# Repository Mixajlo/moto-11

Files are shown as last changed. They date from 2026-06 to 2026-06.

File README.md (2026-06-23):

# moto-11

A modular **ESP32 smart-cockpit, accessory, and security system** for a 2013 Suzuki
V-Strom DL650 — hardware, firmware, harness, and documentation in one repository.

The guiding philosophy is **"fairings off once"**: provision generously now, upgrade in
place later. The ESP32 owns all bike logic; a tablet is a thin display; the phone handles
navigation and connectivity.

---

## What it is

`moto-11` turns the bike into a programmable platform without making any consumer device a
single point of failure:

- **Bike-side controller** — an ESP32-WROOM-32D that is always-hot, deep-sleeps when parked,
  and wakes on ignition. It is the single source of truth for relay control, sensing,
  load management, security, and the parked sentinel.
- **Dashboard** — an Android tablet acting as a *thin* BLE display and an Android Auto
  receiver. UI only; it never decides anything.
- **Phone** — navigation, connectivity, and the BLE relay that drains the bike's event queue
  when it's parked out of network range.

It also folds in the unglamorous-but-important electrical work: a series R/R charging upgrade,
relieving the notorious headlight-through-the-starter-switch wiring, accessory switching via a
relay box driven by a ULN2803, and battery/charging telemetry from an INA226.

## Status

**Early development.** OTA firmware (WiFi + ArduinoOTA + heartbeat) is proven on the bench
across both ESP units. Relay control and the **engine-run supervisor** are in and
bench-validated: a `RelayController` drives the four ULN2803 coil enables (fail-OFF at boot),
a serial/Telnet **bench console** actuates them by hand, and the supervisor runs the power
state machine — `SLEEP → ARMED → RUNNING ⇄ POWERED` (+ `OFF_DELAY`) with ignition-as-master,
a battery backstop, and a charge-health warning — driven by simulated sensors and covered by
unit tests. Next firmware milestone: the real **INA3221** driver + PC817 ignition-sense (then
flip `sim real`), and load-shedding. Hardware is at the bench-prototyping stage (KiCad schematic
+ first-pass PCB). See `docs/adr/` for the decisions made so far.

## Architecture

```
        ┌─────────────┐    BLE     ┌──────────────────────┐
        │   ESP32     │◄──────────►│  Tablet (thin UI +   │
        │ authoritative│            │  Android Auto recv)  │
        │ controller   │            └──────────────────────┘
        └──────┬───────┘                       ▲ projects
   I²C / GPIO / │ relays                        │ Android Auto
  ┌─────────────┼───────────────┐        ┌──────┴──────┐
  │ INA226  IMU  ULN2803  opto   │        │   Phone     │
  │ relay box   master relay     │        │ nav + relay │
  └──────────────────────────────┘        └─────────────┘
```

The ESP runs the bike; the tablet renders; the phone connects. A tablet reboot or removal
degrades only the UI, never the bike's function. Full reasoning is in
[`docs/adr/0001`](docs/adr/0001-esp32-authoritative-controller.md).

## Repository layout

```
moto-11/
├── CLAUDE.md          # project context for Claude Code (read first)
├── firmware/          # PlatformIO ESP32 project        (MIT)
│   ├── platformio.ini
│   ├── src/main.cpp
│   └── include/secrets.h.example
├── hardware/          # KiCad / relay-box as-built       (CERN-OHL-P)
├── harness/           # WireViz source + rendered output
├── docs/              # design docs + decision records    (CC-BY-4.0)
│   ├── electrical-plan.html
│   ├── wiring-schematic.html
│   └── adr/
└── app/               # future tablet / Android Auto app
```

## Hardware

| Area | Choice |
|---|---|
| Controller | ESP32-WROOM-32D (×2: bench twin + bike unit) |
| Charging | Series R/R (Shindengen SH775 / SH847); stock stator, measured first |
| Accessory switch| Pre-wired 4-relay / 6-fuse box, gated by an external master relay |
| Coil driver | ULN2803A (low-side, internal flyback) |
| Sensing | INA226 (bus voltage) + PC817 opto-isolated 12 V inputs + 6-axis IMU |
| Dashboard | Android tablet (Galaxy Tab Active5 target) + phone |

The authoritative electrical design is in `docs/electrical-plan.html` (23 sections) and
`docs/wiring-schematic.html` (single-sheet wiring + ULN2803 driver detail).

## Getting started (firmware)

### Prerequisites
- [VS Code](https://code.visualstudio.com/) with the **PlatformIO IDE** extension
- **Silicon Labs CP210x USB-to-UART driver** (the ESP boards use a CP2102 — without it Windows
  shows no COM port)
- Git

### Clone and open
```bash
git clone https://github.com/<you>/moto-11.git
```
Open the **`firmware/`** subfolder in VS Code (`File → Open Folder → moto-11/firmware`).
PlatformIO expects `platformio.ini` at the root of the opened folder, so open `firmware/`
directly — not the repo root. (Git still tracks the whole repo.) On the first build,
PlatformIO downloads the ESP32 toolchain and framework; let it finish.

### Configure secrets
Copy the template and fill it in — it is gitignored, so your credentials never reach the repo:
```bash
cp include/secrets.h.example include/secrets.h
```
Set `WIFI_SSID`, `WIFI_PASS`, and an `OTA_PASS`. The `OTA_PASS` must match the `--auth=` value
in `platformio.ini`. Avoid `%` and `$` in the OTA password (the config parser treats them
specially).

### Build, flash, monitor
One codebase builds two devices via separate environments (`bench` / `bike`), distinguished by
`DEVICE_NAME`. First flash of each device is over USB:
```bash
pio run -e bench                 # build
pio run -e bench -t upload       # flash over USB
pio device monitor               # serial logs @ 115200
```
Swap `bench` → `bike` for the second unit. (In VS Code, the PlatformIO **Project Tasks** panel
exposes Build / Upload / Monitor per environment — use those rather than the status-bar buttons,
which act on whatever environment is selected.)

### OTA updates
After the first USB flash, update wirelessly:
```bash
pio run -e bench_ota -t upload
```
Set the device's IP (from the serial log) as `upload_port` in the `*_ota` environment if the
`.local` mDNS name doesn't resolve on your OS.

### Windows OTA gotcha
ArduinoOTA needs the ESP to open a connection *back* to your PC. Two things block this on
Windows:
- **Extra network adapters** (WSL/Hyper-V `vEthernet`, VMware, VirtualBox, VPN) — espota can
  advertise the wrong host IP. Disable them so only your real LAN/Wi-Fi adapter is active.
- **A third-party antivirus firewall** — independent of the Windows firewall; pause its network
  shield for the push.

Symptom is `Authenticating…OK` followed by `Waiting for device… No response`. See
[`docs/adr/0008`](docs/adr/0008-ota-ab-rollback.md).

## Documentation

- **[Bench relay guide](https://mixajlo.github.io/moto-11/bench-relay-guide.html)** —
  step-by-step: flash the firmware and click the relays on the bench (just an ESP + USB to
  start). Good first hands-on walkthrough. (Source: `docs/bench-relay-guide.html`.)
- **Design docs** — published via **GitHub Pages** from `/docs`:
  [home](https://mixajlo.github.io/moto-11/),
  [electrical plan](https://mixajlo.github.io/moto-11/electrical-plan.html),
  [wiring schematic](https://mixajlo.github.io/moto-11/wiring-schematic.html).
- **Decision records** (`docs/adr/`) — the *why* behind every major choice, Nygard-format.
- **`CLAUDE.md`** — the condensed project brief; also what Claude Code reads on startup.

## Design principles

- **Colourblind-safe output, always.** Every diagram, chart, and UI uses the Okabe-Ito palette
  and never encodes meaning by colour alone — colour is always paired with line pattern and a
  text label. The maintainer is colourblind; this is a hard constraint.
- **Fail-safe by direction.** Accessories fail **OFF** (safe when the ESP dies); headlights fail
  **ON**. Safety-critical lighting is never solely behind the controller.
- **Bench-twin-first.** Every change is proven on the bench twin before it reaches the bike.

## Licensing

This repo is multi-licensed by content type:

| Path | License |
|---|---|
| `firmware/`  | MIT |
| `hardware/`  | CERN-OHL-P-2.0 |
| `harness/` | CERN-OHL-P-2.0 |
| `docs/` | CC-BY-4.0 |

Full texts live in `LICENSES/`. SPDX identifiers in file headers make this machine-readable;
the [REUSE](https://reuse.software) tool lints it.

## Disclaimer

This project modifies a motorcycle's electrical, charging, and lighting systems. Do this only
if you understand the risks — incorrect wiring can damage the bike, the battery, or yourself,
and some changes (e.g. lighting behaviour) may be subject to local road regulations. Use at your
own risk. Not affiliated with or endorsed by Suzuki.

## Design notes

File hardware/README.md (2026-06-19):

<!-- SPDX-License-Identifier: CERN-OHL-P-2.0 -->
# moto-11 — hardware

KiCad designs and as-built notes for the bike electronics. Licensed **CERN-OHL-P-2.0**
(permissive open hardware) — full text in [`../LICENSES/`](../LICENSES/).

> **Hardware safety:** this drives a motorcycle's 12 V electrical system. Nothing here is
> proven until it's bench-tested per the [bench relay guide](../docs/bench-relay-guide.html).
> Fail-safe direction is non-negotiable: accessories fail **OFF**, headlights fail **ON**.

## Boards

| Board | What it is | Status |
|---|---|---|
| [`mainboard/`](mainboard/) | ESP32-DevKitC carrier + ULN2803 coil driver + sensing front-end (INA226, PC817 opto, IMU) + connectors. Drives the **existing** pre-wired relay/fuse box; it does **not** carry load current. | 📐 design package (pre-KiCad) |

The pre-wired 4-relay / 6-fuse box and the external master relay stay as discrete parts — the
mainboard is the brain that drives their coils and senses the bus. High load current (fog,
grips, tablet) never flows through this PCB.

## How this is organised

Per the chosen workflow, the design is captured as a **text design package** first, then drawn
in KiCad from it:

- [`mainboard/01-schematic-spec.md`](mainboard/01-schematic-spec.md) — the schematic as a
  component list + net-by-net connection table. This is the source of truth for capture.
- [`mainboard/02-bom.csv`](mainboard/02-bom.csv) — bill of materials with part numbers.
- [`mainboard/03-design-rules.md`](mainboard/03-design-rules.md) — board stackup, trace widths
  (sized from real currents), clearances, connectors, mechanical.
- [`mainboard/04-kicad-guide.md`](mainboard/04-kicad-guide.md) — step-by-step to turn the spec
  into a KiCad schematic + PCB, with DRC and fab outputs.

KiCad project files (`*.kicad_pro/_sch/_pcb`) land in `mainboard/` once capture begins.

## Toolchain

**KiCad 10.0.3** is installed on the build machine. Start with
[`04-kicad-guide.md`](mainboard/04-kicad-guide.md). The capture/layout workflow is stable across
KiCad 8–10, so the guide applies regardless of minor version.

## Cross-references

- GPIO pin map: [ADR-0009](../docs/adr/0009-gpio-pin-map.md) (this board adds two pins — see the
  schematic spec's *open decisions*).
- Coil driver rationale: [ADR-0003](../docs/adr/0003-uln2803-coil-driver.md).
- Master-relay gating / fail-safe: [ADR-0004](../docs/adr/0004-master-relay-gating-and-failon-headlights.md).
- Sensing: [ADR-0005](../docs/adr/0005-ina226-sensing.md).
- Authoritative electrical design: [`../docs/electrical-plan.html`](../docs/electrical-plan.html)
  and [`../docs/wiring-schematic.html`](../docs/wiring-schematic.html).

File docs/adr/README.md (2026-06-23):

# Architecture Decision Records

Short records of the significant decisions on **moto-11** — the *why* behind the build, so
future choices (and Claude Code) start with the full context instead of re-deriving it.

One file per decision, named `NNNN-short-title.md`, following Michael Nygard's template
(see `template.md`). A decision's `Status` moves Proposed → Accepted; when a later decision
overturns an earlier one we add a new ADR and mark the old one *Superseded* rather than
editing history.

## Index
- [0001](0001-esp32-authoritative-controller.md) — ESP32 as the authoritative controller; tablet as a thin BLE dashboard
- [0002](0002-series-rr-over-mosfet.md) — Series R/R over a MOSFET (shunt) regulator
- [0003](0003-uln2803-coil-driver.md) — ULN2803 coil driver; commoned pin 86 reused as +12, low-side on pin 85
- [0004](0004-master-relay-gating-and-failon-headlights.md) — External master relay gates the box; headlights stay outside it (fail-ON)
- [0005](0005-ina226-sensing.md) — INA226 for engine-run detection and battery telemetry; sense on a clean lead
- [0006](0006-layered-connectivity.md) — Layered connectivity: phone-relay BLE when parked, tablet radio when riding
- [0007](0007-can-reserved-sds-is-kline.md) — CAN reserved for own modules; the bike's data is K-line SDS, not CAN
- [0008](0008-ota-ab-rollback.md) — OTA with A/B rollback; bench-twin-first
- [0009](0009-gpio-pin-map.md) — ESP32 GPIO pin map: relay enables, ignition sense, I²C
- [0010](0010-twelve-volt-sense-opto.md) — 12 V sense front-end: PC817 opto over a resistor divider
- [0011](0011-ina3221-replaces-ina226.md) — INA3221 (3-channel) in place of the INA226 (amends 0005)
- [0012](0012-ignition-master-switch-powered-state.md) — Ignition-as-master-switch; RUNNING vs POWERED; battery backstop; charge warning (refines §13)
- [0013](0013-runtime-config-nvs-console.md) — Runtime-configurable tunables: NVS-backed, console-edited (BLE/app later)
- [0014](0014-aux-button-inputs-per-gpio.md) — Aux button inputs: one-wire-per-button, per-GPIO, JST-XH connector

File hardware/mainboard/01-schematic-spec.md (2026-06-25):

<!-- SPDX-License-Identifier: CERN-OHL-P-2.0 -->
# Mainboard — schematic specification

The complete schematic as text: functional blocks, a component list with reference
designators, and a **net-by-net connection table**. This is the source of truth for KiCad
capture ([04-kicad-guide.md](04-kicad-guide.md)).

**What this board is:** the brain. It sockets an ESP32-DevKitC, drives the existing relay-box
coils through a ULN2803, senses the 12 V bus (INA3221) and two 12 V logic inputs (PC817 opto),
carries a 6-axis IMU, takes 8 handlebar aux buttons, and makes its own 5 V from the always-hot
battery feed. It carries only control and coil current — **never** load current.

---

## Design decisions (resolved)

1. **ESP mounting = socketed DevKitC** (2× female headers), not a bare WROOM module. Reuses
   your existing boards, keeps USB programming, matches the docs' "USB = programming-only,
   power from buck 5 V" note. *(Bare-module alternative = adds USB-UART + auto-reset + LDO; more
   parts, more risk.)*
2. **12 V sense = PC817 opto — decided.** Chosen over the divider+Zener (electrical-plan Fig 5.1)
   for transient robustness on a noisy bike bus and to keep the input-only GPIOs current-driven.
   Logic inverts (12 V present → GPIO LOW). Recorded in
   [ADR-0010](../../docs/adr/0010-twelve-volt-sense-opto.md). *(The divider+Zener stays a
   documented drop-in if you ever want fewer parts.)*
3. **Two pins added (accepted):** `START_SENSE` = **GPIO35** (input-only, RTC) = 2nd opto channel
   (start-button / headlight-feed sense); `IMU_INT` = **GPIO33** (RTC) = IMU wake-on-motion
   interrupt (deep-sleep wake source). Reflected in `firmware/src/pins.h` and
   [ADR-0009](../../docs/adr/0009-gpio-pin-map.md).
4. **Sensing IC = INA3221 (3-channel), not INA226** — the shipped part changed. Bonus: 3 channels
   → CH1 = battery bus voltage now; CH2/CH3 reserved for per-branch current sensing later (smarter
   load-shed). Watch the **26 V bus-input limit** (vs INA226's 36 V): the sense input gets a clamp
   (D3). Needs an INA3221 firmware driver (different register map). Recorded in
   [ADR-0011](../../docs/adr/0011-ina3221-replaces-ina226.md).
5. **INA3221, IMU, and buck are breakout modules on headers**, not raw chips — keeps this
   hand-solderable. *(All-SMD alternative is denser but needs reflow/hot-air.)*
6. **ULN2803 has 8 channels; only 4 are used.** The other 4 inputs/outputs are broken out to a
   header + terminals for future relays (e.g. the headlight-shed NC relay). "Fairings off once."

---

## Functional blocks

```
 +12V always-hot (fused 2A, external)
        │
   [reverse-polarity P-FET]──[TVS + bulk cap]──┬─────────────► +12V_PROT (board 12V)
        │                                      │
        │                              [MP1584 buck module A3] ──► +5V ──► ESP 5V/VIN
        │                                                                    │
        │                                                          ESP onboard LDO ──► +3V3
        │
 COIL_RAIL +12 (box pin 86, external) ──► ULN2803 COM (pin10, flyback)

 ESP GPIO 13/25/26/27 ─► ULN2803 in1..4 ─► out1..4 ─► coil 85 wires (screw terminals)
 ESP I2C 21/22 ─────────► INA3221 module + IMU module (shared bus, 4k7 pull-ups)
 12V IGN  ─► PC817 U4 ─► GPIO34 (pull-up 3V3)   [LOW when 12V present]
 12V START─► PC817 U5 ─► GPIO35 (pull-up 3V3)   [LOW when 12V present]
 IMU INT  ─────────────► GPIO33 (wake)
 BTN1..8  ─► J8 (JST-XH) ─► GPIO 4/14/16/17/18/19/23/32 (INPUT_PULLUP, active-LOW, RC)
```

---

## Power rails / nets (naming)

| Net | Meaning |
|-----|---|
| `+12V_HOT` | Always-hot battery feed, after the external 2 A inline fuse (board input). |
| `+12V_PROT` | After reverse-polarity FET + TVS — the protected board 12 V. Feeds the buck. |
| `+5V` | Buck output → ESP 5V/VIN pin. |
| `+3V3` | From the ESP DevKitC onboard regulator → powers INA3221, IMU, opto + button pull-ups. |
| `COIL_RAIL` | +12 V coil common (the box's commoned pin 86). Feeds ULN COM. Externally sourced. |
| `GND` | Single board ground; ties to the star ground externally. |

---

## Component list

| Ref | Part | Value / type | Footprint | Notes |
|-----|---|---|---|---|
| A1 | ESP32-DevKitC | ESP32-WROOM-32D module | 2× 1×19 (or 1×15) female header, 2.54 mm, 0.9″/1.0″ rows | Socketed; verify your board's pin count/row spacing. |
| A2 | IMU module | LSM6DSO (pref.) / MPU-6050 breakout | 1×5 (or 1×8) female header, 2.54 mm | 6-axis, I²C, INT out. |
| A3 | Buck module | MP1584EN mini buck | 4-pad (IN+ IN− OUT+ OUT−), 2.54 mm | Pre-set to 5.0 V **and verify** before fitting. |
| U2 | ULN2803A | Darlington array, 8-ch | DIP-18 (socketed) or SOIC-18 | Active-HIGH; COM→COIL_RAIL for flyback. |
| U3 | INA3221 module | CJMCU-3221 3-ch breakout (+ shunts) | `INA3221_Module` (custom, `mainboard.pretty`) — 1×5 labeled edge row | CH1 = bus voltage now; CH2/CH3 reserved for branch current. **26 V input max** → clamp D3. Socketed via the labeled VS/GND/SCL/SDA/A0 row; **confirm count/order** against the silk. |
| U4, U5 | PC817 | Optocoupler, single | DIP-4 | One per 12 V sense channel (IGN, START). |
| Q1 | P-MOSFET | AOD4185 / DMP3017SFG / IRF4905 | DPAK / TO-220 | Reverse-polarity (ideal-diode orientation). |
| D1 | TVS | SMBJ24A (uni, 24 V standoff) | SMB / DO-214AA | Load-dump clamp on +12V_PROT. |
| D2 | LED | green, 3 mm | THT | +3V3 power indicator (optional). |
| D3 | TVS | SMBJ20A (uni, 20 V standoff) | SMB / DO-214AA | Clamp on INA3221 sense input (26 V limit). |
| C1 | Cap | 470 µF / 35 V electrolytic | radial 8 mm | Bulk on +12V_PROT. |
| C2 | Cap | 100 µF / 16 V electrolytic | radial 6.3 mm | Bulk on +5V. |
| C3–C8 | Cap | 100 nF X7R | 0805 / THT | Decoupling: ESP, ULN, INA3221, opto, IMU. |
| C9 | Cap | 10 µF X7R | 0805 / THT | +3V3 bulk near ESP. |
| C10 | Cap | 1 µF | 0805 | RC filter on INA3221 VBUS sense. |
| R1–R4 | Res | 10 kΩ | 0805 / THT | ULN input pull-downs (boot-safe OFF). |
| R5, R6 | Res | 4.7 kΩ | 0805 | I²C SDA/SCL pull-ups to +3V3. |
| R7, R8 | Res | 2.2 kΩ, 0.25 W | THT/1206 | PC817 LED series (12 V side), ~5 mA. |
| R9, R10 | Res | 10 kΩ | 0805 | Pull-ups on GPIO34/35 (opto outputs; input-only pins). |
| R11 | Res | 100 kΩ | 0805 | Q1 gate–source. |
| R12 | Res | 100 Ω | 0805 | Q1 gate series (optional, slew). |
| Dz1 | Zener | 18 V, 0.5 W | SOD-123 / THT | Q1 gate–source clamp. >14.4 V so idle while charging; <20 V Vgs(max). |
| R13 | Res | 220 Ω | 0805 | D2 LED series. |
| R14 | Res | 100 Ω | 0805 | INA3221 sense series (light RC with C10; keep low to avoid bus-measure error). |
| J1 | Term block | 2-pos, 5.08 mm | THT | `+12V_HOT`, `GND` (power in). |
| J2 | Term block | 2-pos, 5.08 mm | THT | `COIL_RAIL` (+12 to box pin86 / ULN COM), `GND`. |
| J3 | Term block | 4-pos, 3.5 mm | THT | Coil outputs → 85 wires: MASTER, FOG, GRIP, SPARE. |
| J4 | Term block | 3-pos, 3.5 mm | THT | `IGN_12V`, `START_12V`, `SENSE_GND`. |
| J5 | Term block | 2-pos, 3.5 mm | THT | INA3221 `VBUS_SENSE` (clean lead to batt +), `GND`. |
| J6 | Header | 1×4, 2.54 mm | THT | I²C expansion: `+3V3`, `SDA`, `SCL`, `GND`. |
| J7 | Header | 2×4, 2.54 mm | THT | ULN spare ch5–8 in/out break-out (future relays). |
| J8 | Connector | JST-XH, 1×9, 2.50 mm | `Connector_JST:JST_XH_B9B-XH-A_1x09_P2.50mm_Vertical` | Handlebar aux buttons: BTN1..8 + common GND (ADR-0014). |
| R15–R22 | Res | 1 kΩ | 0805 / THT | Button series (RC with C11–C18); bench can omit, fit for the bike (noise). |
| C11–C18 | Cap | 100 nF | 0805 / THT | Button RC to GND (debounce/noise); pairs with R15–R22. |
| TP1–TP4 | Test point | — | THT loop | `+12V_PROT`, `+5V`, `+3V3`, `GND`. |

---

## ESP32-DevKitC pin usage (A1)

| GPIO | Net | Direction | Notes |
|---|-----|---|---|
| 13 | `MASTER_EN` | out | → ULN in1 |
| 25 | `FOG_EN` | out | → ULN in2 |
| 26 | `GRIP_EN` | out | → ULN in3 |
| 27 | `SPARE_EN` | out | → ULN in4 |
| 34 | `IGN_SENSE` | in | ← opto U4, pull-up R9. Input-only/RTC (ext0 wake). |
| 35 | `START_SENSE` | in | ← opto U5, pull-up R10. Input-only/RTC. *(added; ADR-0009)* |
| 33 | `IMU_INT` | in | ← IMU INT. RTC (wake-on-motion). *(added; ADR-0009)* |
| 21 | `SDA` | I/O | I²C; pull-up R5. |
| 22 | `SCL` | I/O | I²C; pull-up R6. |
| 4 | `BTN1` | in | ← `J8.1`; INPUT_PULLUP + RC (R15/C11). Active-LOW. *(ADR-0014)* |
| 14 | `BTN2` | in | ← `J8.2`; INPUT_PULLUP + RC (R16/C12). |
| 16 | `BTN3` | in | ← `J8.3`; INPUT_PULLUP + RC (R17/C13). |
| 17 | `BTN4` | in | ← `J8.4`; INPUT_PULLUP + RC (R18/C14). |
| 18 | `BTN5` | in | ← `J8.5`; INPUT_PULLUP + RC (R19/C15). |
| 19 | `BTN6` | in | ← `J8.6`; INPUT_PULLUP + RC (R20/C16). |
| 23 | `BTN7` | in | ← `J8.7`; INPUT_PULLUP + RC (R21/C17). |
| 32 | `BTN8` | in | ← `J8.8`; INPUT_PULLUP + RC (R22/C18). Spare. |
| 5V (VIN) | `+5V` | pwr in | from buck A3. |
| 3V3 | `+3V3` | pwr out | from ESP LDO → board 3V3 rail. |
| GND (×) | `GND` | pwr | tie all DevKitC GND pins. |

> Do **not** feed +5V to VIN while USB is also connected (see electrical-plan §05). On the
> bench, power via USB *or* the buck, not both.

---

## Net-by-net connection table

Every electrical node, listed by net. `A1.13` = DevKitC GPIO13; `U2.1` = ULN2803 pin 1; etc.
Decoupling caps: place one 100 nF physically next to each IC's V+/GND.

### Power & ground
| Net | Connects |
|-----|---|
| `+12V_HOT` | `J1.1`, Q1 **drain**. External 2 A fuse upstream. |
| `+12V_PROT` | Q1 **source**, `D1` cathode (TVS across PROT→GND), `C1+`, `A3.IN+`, `TP1`. |
| `+5V` | `A3.OUT+`, `C2+`, `A1.5V/VIN`, `TP2`. |
| `+3V3` | `A1.3V3`, `U3.VS`/`U3.VCC`, `A2.VCC`, `R5`, `R6`, `R9`, `R10`, `D2`(via R13), `C9+`, `TP3`. |
| `GND` | `J1.2`, `J2.2`, `A3.IN−`, `A3.OUT−`, `A1.GND`, `U2.9`, `U3.GND`, `U4.gnd side`, `U5.gnd side`, `A2.GND`, `J4.SENSE_GND`, `J5.2`, `J6.4`, all cap −, `TP4`. |
| `COIL_RAIL` | `J2.1`, `U2.10 (COM)`. (Externally wired to box pin 86.) |

### Reverse-polarity + TVS (input protection)
| Net | Connects |
|-----|---|
| Q1 gate | → `GND` via `R12` (100 Ω series); `R11` (100 k) gate→source; `Dz1` zener gate→source clamp. |
| `D1` (TVS) | cathode → `+12V_PROT`, anode → `GND` (unidirectional). |

*P-FET reverse-polarity (high-side): **drain = +12V_HOT (battery in), source = +12V_PROT (load)**,
gate to GND via R12. Correct polarity → body diode forward (HOT→PROT), then Vgs ≈ −12 V turns the
channel fully on (tiny drop). Reverse polarity → body diode reverse-biased → blocked. R11 keeps a
defined off-state if the gate floats; Dz1 clamps Vgs against load-dump.*

### Relay coil driver (ULN2803 U2)
| Net | Connects |
|-----|---|
| `MASTER_EN` | `A1.13` → `U2.1`; `R1` (10k) `U2.1`→GND. |
| `FOG_EN` | `A1.25` → `U2.2`; `R2` `U2.2`→GND. |
| `GRIP_EN` | `A1.26` → `U2.3`; `R3` `U2.3`→GND. |
| `SPARE_EN` | `A1.27` → `U2.4`; `R4` `U2.4`→GND. |
| `COIL_MASTER` | `U2.18` → `J3.1` (master relay coil 85). |
| `COIL_FOG` | `U2.17` → `J3.2`. |
| `COIL_GRIP` | `U2.16` → `J3.3`. |
| `COIL_SPARE` | `U2.15` → `J3.4`. |
| ULN COM | `U2.10` → `COIL_RAIL` (internal flyback clamps to +12). |
| ULN GND | `U2.9` → `GND`. |
| spare ch5–8 | `U2.5..8` → `J7` inputs (with their own pull-downs if used); `U2.14..11` → `J7` outputs. |

### I²C bus (INA3221 U3 + IMU A2)
| Net | Connects |
|-----|---|
| `SDA` | `A1.21`, `U3.SDA`, `A2.SDA`, `R5`→+3V3, `J6.2`. |
| `SCL` | `A1.22`, `U3.SCL`, `A2.SCL`, `R6`→+3V3, `J6.3`. |
| `IMU_INT` | `A2.INT` → `A1.33`. |
| INA3221 sense | `J5.1` (`VBUS_SENSE`) → `R14` (100 Ω) → INA3221 **CH1** input; `C10` CH1→GND (light filter); `D3` (TVS) CH1→GND (26 V clamp). Tie CH1 VIN+/VIN− to the sense node for a zero-current voltage read. |
| INA3221 CH2/CH3 | Reserved — leave on the module terminals for future per-branch current sensing. |

> INA3221 measures bus voltage on a **clean dedicated lead to battery +** (zero current = no IR
> drop), per ADR-0005/0011. Default I²C address **0x40** (A0→GND) — same as the old INA226, so no
> firmware address change, but the **register map / driver differs**. Verify CH wiring against
> your specific breakout's silkscreen. Populate shunts only when you want branch current.

**INA3221 module header pin map (U3) — socketed via the LABELED edge row; CONFIRM count/order
against the board silk.** The custom `INA3221_Module` footprint is a 1×5 row matching that
labeled edge. Pad names live in the schematic symbol, so if your silk order differs just remap
the symbol pins (or rotate 180°). `A0→GND` sets I²C address **0x40**. The alert pins
(PV/WARN/CRIT/TC) and CH2/CH3 terminals are left unconnected here — we read everything over I²C.

| Pad | Silk label (assumed) | Net |
|-----|---|-----|
| 1 | VS  | `+3V3` |
| 2 | GND | `GND` |
| 3 | SCL | `SCL` |
| 4 | SDA | `SDA` |
| 5 | A0  | `GND` (address 0x40) |

### Aux buttons — handlebar (J8, ADR-0014)
Dry contacts, **active-LOW**: each button shorts its GPIO to GND when pressed; the ESP's
internal pull-up idles it HIGH. Debounced in firmware (`src/buttons.cpp`). The per-line RC
(series R15–R22 + C11–C18 to GND) filters bus noise on the bike run — optional on the bench.

| Net | Connects |
|-----|---|
| `BTN1` | `J8.1` → `R15` (1k) → `A1.4`; `C11` (100n) node→GND. |
| `BTN2` | `J8.2` → `R16` → `A1.14`; `C12`→GND. |
| `BTN3` | `J8.3` → `R17` → `A1.16`; `C13`→GND. |
| `BTN4` | `J8.4` → `R18` → `A1.17`; `C14`→GND. |
| `BTN5` | `J8.5` → `R19` → `A1.18`; `C15`→GND. |
| `BTN6` | `J8.6` → `R20` → `A1.19`; `C16`→GND. |
| `BTN7` | `J8.7` → `R21` → `A1.23`; `C17`→GND. |
| `BTN8` | `J8.8` → `R22` → `A1.32`; `C18`→GND. |
| button GND | `J8.9` → `GND` (common return for all 8 buttons). |

> Pull-ups are the ESP's internal ones (`INPUT_PULLUP`), so no external pull-up resistors are
> needed. Keep the RC light (1 kΩ / 100 nF ≈ 0.1 ms) — far faster than the 25 ms firmware
> debounce, so it only knocks down spikes. Past 8 buttons → swap to an MCP23017 on I²C (ADR-0014).

### 12 V sense — opto-isolated (PC817 U4 = IGN, U5 = START)
PC817 pins: 1 = anode (LED+), 2 = cathode (LED−), 3 = emitter, 4 = collector.

| Net | Connects |
|-----|---|
| `IGN_12V` | `J4.1` → `R7` (2k2) → `U4.1`; `U4.2` → `SENSE_GND` (`J4.3`). |
| IGN out | `U4.4` (collector) → `+3V3` via `R9` (10k) **and** → `A1.34`; `U4.3` (emitter) → `GND`. |
| `START_12V` | `J4.2` → `R8` (2k2) → `U5.1`; `U5.2` → `SENSE_GND`. |
| START out | `U5.4` → `+3V3` via `R10` **and** → `A1.35`; `U5.3` → `GND`. |

> Inverted logic: 12 V present → opto LED on → transistor pulls the GPIO **LOW**. Firmware reads
> `engineRunning`/start with this inversion in mind. `SENSE_GND` ties to board `GND`.

### Indicator
| Net | Connects |
|-----|---|
| pwr LED | `+3V3` → `R13` (220Ω) → `D2.anode`; `D2.cathode` → `GND`. |

---

## Sanity checks baked in
- **Boot-safe:** R1–R4 hold ULN inputs low while the ESP boots → all relays OFF (fail-OFF).
- **No external flyback diodes:** ULN COM→COIL_RAIL uses the chip's internal clamps (ADR-0003).
- **Input-only pins fed:** GPIO34/35 have no internal pull-ups, so R9/R10 are mandatory.
- **One ground:** single `GND` net, star-tied off-board; sense grounds returned here.
- **Decoupling:** a 100 nF within ~5 mm of every IC power pin; bulk where rails enter.

Next: [02-bom.csv](02-bom.csv) · [03-design-rules.md](03-design-rules.md) · [04-kicad-guide.md](04-kicad-guide.md)

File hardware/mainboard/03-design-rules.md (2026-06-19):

<!-- SPDX-License-Identifier: CERN-OHL-P-2.0 -->
# Mainboard — design rules, stackup & mechanical

Constraints for the KiCad PCB. These are chosen for a **low-current control board** in an
automotive (vibration + thermal + transient) environment, fabbed cheaply at JLCPCB/PCBWay.

## Currents on this board (why the traces are modest)

This board does **not** carry load current. The worst-case currents it sees:

| Path | Current | Notes |
|---|---|---|
| `+12V_HOT` → buck | < 0.5 A | ESP + peripherals via the 5 V buck. |
| `COIL_RAIL` / coil outputs | ~0.15–0.2 A each, ≤ ~1 A total | Relay coils; brief inrush. |
| `+5V` | < 0.6 A | ESP peak (WiFi TX bursts). |
| `+3V3` | < 0.3 A | Sensors + opto pull-ups. |
| Sense / signal | µA–mA | INA226 lead, opto, I²C, IMU. |

So the dominant sizing factor is **robustness**, not heat: wide power traces and a solid ground
pour resist vibration fatigue and give clean returns, even though the amps are small.

## Trace widths (1 oz / 35 µm copper, ≤ 10 °C rise)

| Class | Nets | Width | Rated (10 °C rise) |
|---|---|---|---|
| Power | `+12V_HOT`, `+12V_PROT`, `+5V`, `COIL_RAIL`, coil outputs | **1.5 mm** (≈ 59 mil) | ~3 A — generous margin |
| 3V3 rail | `+3V3` | **0.8 mm** | ~1.7 A |
| Signal | GPIO, I²C, opto, INT | **0.30 mm** (≈ 12 mil) | ample |
| Ground | copper **pour** both layers, stitched | — | star-tied off-board |

> Going wider than strictly needed on power is deliberate — it costs nothing and buys vibration
> and transient headroom on a bike.

## Clearances & rules (JLCPCB 2-layer default-safe)

- Min track / clearance: **0.2 mm** (8 mil) — well within fab capability; use 0.25 mm where space allows.
- **12 V-to-anything clearance: ≥ 0.5 mm**; **opto isolation barrier: keep ≥ 4 mm** creepage
  between the 12 V (input) side and the logic (output) side of U4/U5 — do not pour ground under
  the barrier.
- Min via: 0.3 mm drill / 0.6 mm pad. Vias: 0.4/0.8 for power.
- Hole-to-copper: 0.25 mm. Silk min: 0.15 mm / 1 mm text height.

## Stackup

- **2-layer**, 1.6 mm FR-4, 1 oz copper, HASL (lead-free) finish.
- Top: components + signal; Bottom: ground pour + power fills + a few signal jumpers.
- Ground pour on **both** layers, stitched with vias every ~10 mm and around the ESP/RF area.

## Board outline & mechanical

- Target **~90 × 70 mm** (fits DevKitC ~55 × 28 mm + ULN + module headers + terminal blocks on
  one edge). Adjust after placement.
- **4× M3 mounting holes**, 4 mm from corners, with keep-out and a ground stitch ring (chassis
  option via a 0 Ω / ferrite, default isolated — star ground only).
- **Terminal blocks on one board edge** (J1–J5) so field wiring enters from one side; pluggable
  type preferred for serviceability.
- Keep the **DevKitC antenna end overhanging the board edge** (no copper under the PCB-antenna
  keep-out) — critical for WiFi/BLE range.
- USB port of the DevKitC must remain **physically accessible** for reflashing (orient the
  socket so USB faces a board edge; see electrical-plan §05 service-loop note).

## RF / analog hygiene

- ESP32 antenna keep-out: no copper (any layer) under/around the WROOM antenna cutout.
- Route I²C as a pair, away from the buck switch node; keep INA226 sense (`VBUS_SENSE`/`R14`/`C10`)
  short and away from the buck.
- Place buck input/output bulk caps tight to A3; keep the buck's high-di/dt loop small.
- One 100 nF per IC power pin, within ~5 mm.

## Fabrication

- House rules: **JLCPCB** (cheap, 2-layer). Generate Gerbers + drill + a centroid/BOM if you
  later want assembly; for hand-assembly, Gerbers + drill are enough.
- Panelization: none needed (single board).
- Export step is in [04-kicad-guide.md](04-kicad-guide.md) §7.

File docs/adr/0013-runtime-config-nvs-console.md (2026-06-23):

# 13. Runtime-configurable tunables: NVS-backed, edited via the console (BLE/app later)

- Status: Accepted
- Date: 2026-06-23
- Deciders: Miki

## Context
The supervisor has several tunables — voltage thresholds (`vRunOn`, `vRunOff`,
`chargeWarn`, `chargeClear`) and timers (`runDebounce`, `stallDebounce`, `offDelay`,
`backstop`, `chargeDebounce`) — and more are coming (button→action mappings). The
owner will want to adjust these **without reflashing**, ideally from the tablet
eventually. Today they're compile-time constants in `supervisor.h`. We need
persistence across reboot/OTA and a way to edit them, starting as simply as possible.

## Decision
A small **`Config` module backed by ESP32 NVS** (via the Arduino `Preferences`
library). NVS is a dedicated key/value flash partition (~20 KB), purpose-built for
this; our config is a few dozen bytes, with wear-leveling and survival across reboot
and OTA (separate partition).

- **Defaults live in firmware** (`supervisor.h`) and are the fallback. At boot,
  `Config` loads NVS; if a key is absent or the stored **schema version** doesn't
  match, the compile-time default is used. Loaded values are applied to `Engine`.
- **Edit via the existing serial/Telnet console** first — `config` (dump), `get
  <key>`, `set <key> <value>`, `config reset` (restore defaults). This is the
  simplest interface and needs no new hardware; it also forces us to build the
  validation core that later front-ends reuse.
- **Validate every write**: clamp to sane min/max and **enforce the ladder**
  `vRunOff < vRunOn < chargeWarn < chargeClear`. Reject/clamp invalid input; never
  persist an inconsistent set. A corrupt NVS falls back to safe firmware defaults.
- **Layered access, one backend:** console now → **BLE GATT** characteristics
  (tablet) → a future **Android config app** — all read/write the same `Config`/NVS
  core. (Roadmap.)

## Consequences
- Tune on the bench or bike with no reflash; changes persist and are OTA-safe.
- Fail-safe by construction: firmware defaults are the floor; validation blocks
  footguns (e.g. `offDelay` absurdly large, or thresholds out of order).
- Negligible flash wear (writes only on change).
- The console layer is testable now; BLE/app are later UI on top.
- Adds a tiny module + a schema-version constant to bump when the config shape changes.

## Alternatives considered
- **Hardcoded constants (reflash to change):** what we have — rejected; the owner
  needs field adjustment.
- **SPIFFS/LittleFS JSON file:** heavier than needed for ~10 scalars; NVS is simpler
  and more robust for key/value.
- **Legacy EEPROM emulation:** superseded by NVS on ESP32.
- **BLE/app first:** more work before any payoff; the console backend is the
  prerequisite anyway, so it goes first.

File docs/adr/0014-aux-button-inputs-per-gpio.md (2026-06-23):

# 14. Aux button inputs: one-wire-per-button, read per-GPIO, on a JST-XH connector

- Status: Accepted
- Date: 2026-06-23
- Deciders: Miki

## Context
A motorcycle handlebar switch case (7 buttons — 5 front, 2 back) will drive aux
loads (fog, grips, spare, …) from the bars. The buttons are **dry contacts** (simple
switch closures, no power). The owner wants **one wire per button** run from the bars
to the ESP, a connector on the mainboard to plug the cable into, and headroom to add
a few more buttons later. (Whether each is momentary or maintained is to be confirmed
when the case is in hand — it changes firmware interpretation, not the wiring.)

## Decision
- **Wiring:** one conductor per button from the case to the mainboard, sharing a
  **common ground**, landing on a keyed **JST-XH** connector (serviceable unplug).
  Provision **8 button inputs + GND** (7 used now, 1 spare).
- **Read per-GPIO:** assign 8 free, pull-up-capable GPIOs —
  **`4, 14, 16, 17, 18, 19, 23, 32`** (`BTN1..BTN8`). **Active-low**: enable the
  internal pull-up, the button closes the line to GND (pressed = LOW). Add a small
  **RC filter** per line + **firmware debounce**. No opto-isolation — they're dry
  contacts referenced to our ground.
- **Buttons are inputs that drive the relay outputs** (master/fog/grip/spare + the
  spare ULN channels). The **button → action mapping is runtime config**
  ([ADR-0013](0013-runtime-config-nvs-console.md)) — default mapping TBD. Firmware
  supports both **momentary** (press = toggle / step) and **maintained** (position =
  state) switches; the exact handling is set once the switch type is validated.
- **Upgrade path:** the per-GPIO ceiling is ~8–10 clean pins. Because the harness is
  one-conductor-per-button into a connector, outgrowing it is a **board-rev swap to an
  MCP23017 I²C expander** (16 inputs + INT on the existing I²C bus) — route the same
  connector pins to the expander instead of the GPIOs, **no change to the bike harness**.

## Consequences
- Simplest firmware and lowest latency; works on the bench immediately (a jumper to
  GND on a BTN pin = a press).
- Consumes most of the remaining ESP GPIOs — accepted; future peripherals that need
  pins should go on I²C (and a button move to the MCP23017 frees the GPIOs back).
- RTC-capable pins among the set (4, 14, 32) keep a future **wake-on-button** option
  open without extra cost.
- Adds an 8-way JST-XH + 8 RC networks to the board (provision now, since the PCB
  isn't fabbed). The `pins.h` map and the mainboard schematic spec gain the BTN lines.

## Alternatives considered
- **MCP23017 I²C expander now:** more scalable (16 in, 1 INT, no GPIO cost) but more
  board complexity than needed for 7–8 buttons; kept as the documented upgrade path.
- **Resistor ladder on one ADC pin (fewest wires):** rejected — ESP32 ADC is noisy/
  non-linear, only one button at a time is unambiguous; poor fit for handlebar use.
- **Remote button module over CAN/serial:** v2 overkill for a short handlebar run.
- **Switched-12 V or illuminated buttons:** would need LED power + opto-isolation;
  not these buttons (dry contacts), but the connector can be widened later if needed.

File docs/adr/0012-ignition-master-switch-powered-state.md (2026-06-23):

# 12. Power management: ignition-as-master-switch, RUNNING vs POWERED, battery backstop, charge warning

- Status: Accepted (refines the state logic in `electrical-plan.html` §13)
- Date: 2026-06-23
- Deciders: Miki

## Context
The original supervisor (electrical-plan §13) was a 4-state machine —
`SLEEP → ARMED → RUNNING → OFF_DELAY` — that left `RUNNING` **only** on
ignition-off. Bench testing against real riding scenarios surfaced gaps:

- **Stall / kill-switch:** engine stops but the key stays on. The rider wants to
  flip the kill switch / restart and carry on — accessories should **stay
  powered**, not cut.
- **Short stop (e.g. buying something), engine off, key left on for > 30 s:** the
  rider does **not** want the 30 s off-delay to cut power; they'll be back and
  restart with no interruption.
- **Engine-only loads:** heated grips shouldn't run when the engine isn't running
  (no charging) — so the firmware must distinguish "engine actually charging" from
  "key on, engine off."
- **Weak charging:** with several loads on, the bus can sit below a healthy charge
  voltage while the engine runs — the rider wants an early warning (this is a core
  reason the INA3221 sensing exists).

The original logic handled none of these: a stall left it stuck in `RUNNING`, and
the only exit was key-off → off-delay → cut.

## Decision
**The ignition key is the master switch.** Once powered, accessories stay on until
the key goes **OFF**. Engine-run (`Vbus ≥ V_RUN_ON`, debounced) only gates the
*first* power-on and distinguishes two live states. New machine:

`SLEEP → ARMED → RUNNING ⇄ POWERED`, plus `OFF_DELAY` on key-off.

- **RUNNING** — key on **and** engine running (charging); MASTER on. `engineRunning()`
  is true here only; engine-only loads (grips) gate on it.
- **POWERED** — key on, engine **off** (stall / kill / stop); MASTER **stays on** so
  a restart is seamless. Distinct from RUNNING so engine-only loads can shed.
- **Battery-save backstop** — if POWERED persists (engine off, key on) for a long
  time (default **10 min**, tunable; 0 = off), cut MASTER → ARMED to protect the
  battery from a forgotten key. Far longer than any normal stop, so it never bites.
- **OFF_DELAY** — entered only on key-off; holds MASTER for the delay (default 30 s)
  so a quick key-cycle/restart keeps power, then cuts and sleeps.
- **Charge-health warning** — while RUNNING, a marginal-charging warning ("loads too high or
  R/R weak") with a latched `chargeMarginal()` flag for a future tablet alert / load-shed. To
  avoid false triggers from bus ripple and brief load-switch dips near the threshold, it uses
  **hysteresis + debounce**: go marginal when `Vbus < CHARGE_WARN` (13.4 V) sustained 5 s; clear
  when `Vbus >= CHARGE_CLEAR` (13.6 V) sustained 5 s; the 13.4–13.6 deadband holds state between.
  The INA3221 driver will additionally hardware-average samples to pre-filter noise. Clean ladder
  (no overlap): `V_RUN_OFF 12.9 < V_RUN_ON 13.2 < CHARGE_WARN 13.4 < CHARGE_CLEAR 13.6`.

All thresholds and timers are tunables, intended to become tablet-configurable over
BLE (persisted to NVS) — see the roadmap.

## Consequences
- Behaviour matches real riding: stalls, kill-switch use, and short stops keep
  accessories powered; restart is seamless.
- The battery is still protected — by the long POWERED backstop (forgotten key) and
  the key-off off-delay → sleep — without nagging normal short stops.
- A clean `engineRunning()` signal lets load policy hold engine-only loads (grips)
  off when not charging. *(The actual grip-shed policy is a later `manageLoads()`
  step; the hook exists now.)*
- Early warning of marginal charging — the practical payoff of bus-voltage sensing.
- State machine grows 4 → 5 states; §13 pseudocode updated to match.
- Idle-sag risk: heavy load at idle can momentarily dip `Vbus`. Mitigated by
  hysteresis (`V_RUN_ON` 13.2 / `V_RUN_OFF` 12.9) plus run/stall debounces; the
  charge warning is informational and never cuts power.

## Alternatives considered
- **Keep the original §13 (cut on key-off only, no POWERED):** can't distinguish
  engine-running for load policy and gives no charge warning; also leaves a stall
  stuck in RUNNING. Refined by this ADR.
- **Strict engine-run gating (cut accessories whenever the engine stops):**
  rejected — it would cut power on every stall and short stop, rebooting the tablet
  and contradicting the rider's needs.
- **No backstop (trust the rider to kill the key):** rejected — a forgotten key
  would flatten the battery; the 10 min backstop is cheap insurance that never
  interferes with normal use.

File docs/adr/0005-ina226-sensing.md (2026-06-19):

# 5. INA226 for engine-run detection and battery telemetry; sense on a clean lead

- Status: Accepted — **part amended by [ADR-0011](0011-ina3221-replaces-ina226.md)** (INA3221)
- Date: 2026-06-19
- Deciders: Miki

> The sensing *architecture* below stands; only the device changed (INA226 → INA3221, a
> 3-channel superset). See ADR-0011 for the 26 V input limit and firmware-driver consequences.

## Context
The controller must (a) tell *running* from *key-on, engine-off*, without being fooled by a
battery tender; (b) judge battery health; and (c) drive voltage-based load-shedding. A panel
voltmeter recently fitted to the bike read ~1 V low because it was spliced into a
load-carrying ignition wire.

## Decision
Use an **INA226 over I²C** for bus voltage. Engine-run is
`engineRunning = ignitionHIGH && (Vbus >= 13.2 V)`. Battery telemetry uses the **rate of
change** — a fast drop after parking means a load left on; a slow sag over days means it just
sat — sampled when settled (a 24 h timer firing in the early morning). **Always sense on a
dedicated lead to the battery +** (only microamps flow, so no IR drop); never on a
load-carrying wire. A **PC817 2-channel opto** isolates two 12 V inputs into the ESP:
ignition/run-sense and start-button/headlight-feed sense (logic inverts).

## Consequences
- Engine-run detection is unambiguous — a charger can't fake it because the key is off.
- Voltage readings are true (no IR drop); the tablet readout becomes the accurate "voltmeter,"
  superseding the panel meter.
- Battery alerts are trend-based rather than single-threshold.
- The cheap INA226 module's default 0.1 Ω shunt maxes at ~0.8 A — fine for voltage-only; for
  current measurement use a low-value (~2 mΩ) shunt.

## Alternatives considered
- **Ignition-only detection**: rejected — can't distinguish running from key-on.
- **Voltage-only detection**: rejected — a tender fools it.
- **Panel voltmeter on a switched accessory wire**: rejected — the IR drop that caused the ~1 V
  error; sense must be on a current-free lead.

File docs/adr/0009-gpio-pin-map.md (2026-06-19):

# 9. ESP32 GPIO pin map for relay enables, ignition sense, and I²C

- Status: Accepted
- Date: 2026-06-19
- Deciders: Miki

## Context
The wiring schematic fixes the *logical* signals — `MASTER_EN`, `FOG_EN`, `GRIP_EN`,
`SPARE` (active-HIGH into the ULN2803A), `IGN_SENSE` (a wake input), and an I²C bus for the
INA226 and IMU — but never bound them to physical ESP32 pins. The firmware needs concrete
GPIO numbers, and the choice is constrained: the ESP32-WROOM-32D has strapping pins
(0, 2, 5, 12, 15) that must hold particular levels at boot, flash pins (6–11) that are
unusable, and input-only pins (34, 35, 36, 39) with no internal pull and no output driver.
Relay enables must additionally sit **LOW at boot** so no coil energises before `setup()`
runs (accessory fail-OFF), and `IGN_SENSE` must be on an **RTC-capable** pin so it can wake
the ESP from deep sleep via `ext0`.

## Decision
We will use this map (defined once in `firmware/src/pins.h`):

| Signal | GPIO | Notes |
|---|---|---|
| `MASTER_EN`  | 13 | low at boot; not strapping/flash |
| `FOG_EN` | 25 | low at boot |
| `GRIP_EN` | 26 | low at boot |
| `SPARE_EN` | 27 | low at boot |
| `IGN_SENSE`  | 34 | input-only, RTC-capable → `ext0` ignition wake |
| `START_SENSE`| 35 | input-only, RTC-capable; start-button / headlight-feed sense |
| `IMU_INT` | 33 | RTC-capable; IMU wake-on-motion (deep-sleep wake source)  |
| `I2C_SDA` | 21 | Arduino-ESP32 default SDA (INA3221 + IMU) |
| `I2C_SCL` | 22 | Arduino-ESP32 default SCL |
| `LED` | 2 | onboard LED — heartbeat / bench relay-activity indicator  |

The ULN2803A inputs 1–4 are wired to GPIO 13/25/26/27 in that channel order. The owner
wires the bench ULN to match this map.

**Amendment (2026-06-19):** added `START_SENSE` (GPIO35) and `IMU_INT` (GPIO33) for the
mainboard ([hardware/mainboard](../../hardware/mainboard/)). Both are RTC-capable; GPIO35 is
input-only like GPIO34 (driven by the second PC817 opto channel — see [ADR-0010](0010-twelve-volt-sense-opto.md)),
and GPIO33 takes the IMU motion-wake interrupt. The 12 V senses are opto-isolated, not a passive
divider; see ADR-0010.

## Consequences
- Relays are guaranteed OFF through boot: the chosen output pins are low at reset and the
  ULN inputs also carry 10 kΩ pull-downs (ADR-0003) — defence in depth for fail-OFF.
- `IGN_SENSE` on GPIO 34 keeps the deep-sleep wake path open without burning a general-
  purpose pin; being input-only is fine because the ignition front-end is a passive divider.
- GPIO 2 is the onboard LED *and* a strapping pin; using it only as an output indicator (not
  driving it during reset) is safe and frees no constraint we need elsewhere.
- Plenty of headroom remains (e.g. 14, 32, 33, 4, 16, 17) for the headlight-shed NC relay,
  the second PC817 sense channel, CAN TWAI, and future loads.

## Alternatives considered
- **Putting a relay enable on GPIO 2/4/5/12/15** (strapping/onboard-LED pins): rejected — a
  HIGH on a strapping pin at reset can change boot mode or flash voltage, and any glitch
  risks a coil twitching at power-up. The relay lines must be boot-quiet.
- **`IGN_SENSE` on a non-RTC GPIO** (e.g. 16/17): rejected — it would forfeit `ext0`
  deep-sleep wake on ignition, which is core to the parked-sentinel design.
- **Non-default I²C pins**: rejected — no reason to deviate from 21/22; staying on the
  Arduino default avoids a `Wire.begin(sda, scl)` footgun later.

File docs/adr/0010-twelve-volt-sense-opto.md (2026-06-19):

# 10. 12 V sense front-end: PC817 opto-isolation over a resistor divider

- Status: Accepted
- Date: 2026-06-19
- Deciders: Miki

## Context
The ESP must read two 12 V logic signals — **ignition/run-sense** (also a deep-sleep `ext0`
wake source) and **start-button / headlight-feed sense**. The project docs disagreed on how:
`electrical-plan.html` Fig 5.1 shows a **resistor divider (100k/27k) + 3.3 V Zener clamp + RC
filter** into the GPIO, while `CLAUDE.md` specifies a **PC817 opto-isolator**. Both land a safe
level on the pin, so the question is which is the better front-end for a motorcycle's 12 V bus —
which is electrically hostile: load-dump, relay/coil inductive kickback, and alternator ripple.
The chosen sense pins (GPIO34/35) are also **input-only**, with no internal pull-ups and only
pad-level protection.

## Decision
We will use a **PC817 optocoupler per channel** (U4 = ignition, U5 = start/headlight). The 12 V
side drives the opto LED through a series resistor (~2.2 kΩ, ~5 mA); the output transistor pulls
the GPIO to GND through a 10 kΩ pull-up to 3.3 V. **Logic inverts: 12 V present → GPIO LOW.**
Firmware reads the senses with that inversion. The resistor-divider+Zener remains documented as
a drop-in alternative if a future board wants fewer parts.

## Consequences
- Strong transient immunity: bus spikes are absorbed by the opto LED / series resistor, not
  coupled into the input-only GPIO.
- Current-loop signalling gives clean, debounced edges — good for the `ext0` ignition wake.
- Firmware must invert the two sense inputs (trivial); document it at the read site.
- PCB cost: two optos + four resistors, and a **≥ 4 mm isolation gap** must be kept clear under
  U4/U5 (no ground pour across the barrier) — captured in the mainboard design rules.
- Galvanic isolation is partly moot (ESP and bike share ground); the win here is robustness, not
  isolation per se.

## Alternatives considered
- **Resistor divider + Zener clamp + RC** (electrical-plan Fig 5.1): fewer/cheaper parts and
  non-inverted, but directly couples the noisy bus to a sensitive input-only pin and leans on a
  small Zener to survive repeated transients. Kept as the documented fallback.
- **Divider into a protected GPIO with a series resistor only**: simplest, but least robust to
  load-dump — rejected for an always-connected automotive device.

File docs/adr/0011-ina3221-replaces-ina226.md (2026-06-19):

# 11. INA3221 (3-channel) in place of the INA226 for bus sensing

- Status: Accepted (amends [ADR-0005](0005-ina226-sensing.md))
- Date: 2026-06-19
- Deciders: Miki

## Context
[ADR-0005](0005-ina226-sensing.md) chose the **INA226** for trustworthy bus-voltage (and
optional current) sensing over I²C, read on a clean dedicated lead to battery + (zero current =
no IR drop). The supplier shipped an **INA3221** instead. Rather than re-order, we evaluated the
INA3221 in its place — it is a related TI part, so the sensing *architecture* (I²C, clean sense
lead, engine-run detection) is unchanged; only the device differs.

## Decision
We will use the **INA3221** as the bus monitor. It is a **3-channel** voltage/current monitor:
- **CH1** = battery bus voltage (the role the INA226 had) — drives engine-run detection and
  battery telemetry.
- **CH2 / CH3** = reserved for future **per-branch current** sensing (e.g. fog and grip
  branches), enabling smarter, targeted load-shedding than a single bus reading allows.

Default I²C address is **0x40** (A0 → GND), the same as the INA226 default, so no address change.

## Consequences
- **Free upgrade path:** two extra measurement channels we didn't have, fitting the
  "provision generously" philosophy at no extra board cost.
- **Lower input ceiling:** INA3221 bus inputs are rated to **26 V** (vs INA226's 36 V). The bike
  bus is ~12–14.4 V, but load-dump transients exceed 26 V, so the sense input gets a **TVS clamp
  (D3, ~20 V)** plus a small series R — captured in the mainboard schematic spec.
- **Firmware driver changes:** the register map differs from the INA226; the (not-yet-written)
  sensing driver targets an INA3221 library. The I²C address and bus wiring are unchanged.
- Keep the sense series resistance **low** (≈100 Ω, not 100 k) to avoid bus-measurement error
  from the device's input behaviour.

## Alternatives considered
- **Re-order an INA226** to match ADR-0005: avoidable delay and cost; the INA3221 is a strict
  superset for our needs (more channels), so no reason to wait.
- **Bare ADC divider** (no INA part): rejected in ADR-0005 already (ESP32 ADC is noisy/non-linear);
  unchanged.

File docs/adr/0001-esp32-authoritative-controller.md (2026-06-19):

# 1. ESP32 as the authoritative controller; tablet as a thin BLE dashboard

- Status: Accepted
- Date: 2026-06-19
- Deciders: Miki

## Context
The cockpit needs a brain that owns all bike logic — relay control, sensing, security,
state machines, the off-delay and parked sentinel. A tablet is attractive as a display, but
it is a consumer device: it reboots, suspends apps, throttles on heat, and can be unplugged
or stolen. Putting safety- and function-critical logic on it would make the bike's behaviour
hostage to an app lifecycle.

## Decision
The **ESP32-WROOM-32D is the single source of truth** for all bike logic. It is always-hot,
deep-sleeps when parked, and wakes on ignition. The **tablet is a thin BLE display and an
Android Auto receiver — UI only, it never decides anything.** The **phone** handles
navigation and connectivity. Control flows ESP → (BLE) → tablet for display; the tablet sends
only user intents back.

## Consequences
- Bike function survives a tablet reboot, crash, removal, or theft — only the UI degrades.
- The ESP must be robust and self-sufficient (watchdog, sane defaults, deep-sleep budget).
- Adds a BLE link and a small GATT contract to design and maintain.
- Clean separation of concerns: hard real-time and safety on the ESP, presentation on the tablet.

## Alternatives considered
- **Tablet/Android-centric** (apps drive the bike): rejected — unreliable for anything
  safety-relevant, and hostage to Android's app lifecycle and thermal behaviour.
- **Raspberry Pi controller**: rejected — higher idle power, slow boot, SD-card reliability,
  and overkill for the control task.

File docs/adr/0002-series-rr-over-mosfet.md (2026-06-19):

# 2. Series R/R over a MOSFET (shunt) regulator

- Status: Accepted
- Date: 2026-06-19
- Deciders: Miki

## Context
The DL650 ships with a **shunt-type** regulator/rectifier: the stator produces near-maximum
output continuously and the R/R dumps the excess to ground as heat, so the stator runs hot
regardless of electrical draw — a known weak point on this generation. We are adding
accessory load and want both reliable charging headroom and reduced stator stress.

## Decision
Upgrade to a **series regulator (Shindengen SH775 ≈ 35 A, or SH847 ≈ 50 A)** — not a MOSFET
unit. A MOSFET R/R (e.g. FH012AA) is still a *shunt* regulator: it runs the R/R cooler but
leaves the stator at full output. A **series** R/R disconnects the stator when charge isn't
needed, which is the actual stator-heat reduction. The SH775 is right-sized for the 650; the
**SH847 is the genuine OEM series unit (Suzuki PN 32800-31J00)**. Buy genuine — counterfeit
SH847s are shunt units in disguise.

## Consequences
- Lower stator temperature and longer life; genuine charging headroom for accessories.
- Requires hardwiring (ditch the OEM connectors), 10 AWG output on a 30 A fuse, and a sense
  lead to battery +. Healthy result ~14.2–14.4 V at the battery.
- Counterfeit risk means sourcing care (Suzuki PN, Japanese-made, metal base, Shindengen logo).
- The stator itself is **not** pre-emptively replaced — it is measured first (see ADR-0005).

## Alternatives considered
- **MOSFET R/R (FH012AA / FH020AA)**: rejected — cooler R/R but still shunt, so the stator
  stays hot.
- **Leave the stock shunt R/R**: rejected — the heat issue plus added accessory load.

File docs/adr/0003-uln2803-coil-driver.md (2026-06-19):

# 3. ULN2803 coil driver; commoned pin 86 reused as +12, low-side on pin 85

- Status: Accepted
- Date: 2026-06-19
- Deciders: Miki

## Context
The pre-wired relay/fuse box has four relays whose coil **negatives (pin 86, black) come
commoned**, with the individual coil **positives (pin 85, white)** brought out separately.
The ESP must drive four coils individually from 3.3 V logic, and these relays have no coil
suppression of their own.

## Decision
Reuse the commoned **pin 86 as the +12 V coil rail** and **low-side switch each white/85 wire
to ground**, one channel per relay (coils are non-polarised, so swapping +/- is fine). Drive
them with a **ULN2803A Darlington array**: open-collector low-side sink, 3.3 V-logic inputs,
**active-HIGH** (GPIO high → output sinks the 85 line → relay pulls in). Tie the ULN's
**COM (pin 10) to the +12 rail** so its **internal clamp diodes handle flyback — no external
1N4007s**. A 10 kΩ pull-down on each input keeps relays off while the ESP boots.

## Consequences
- No need to cut/separate the factory coil common.
- No discrete flyback diodes on the box (built into the ULN via COM→+12).
- Firmware logic is active-high; relays only actuate when the box is powered (engine running).
- ~1 V Darlington drop → the coil sees ~11 V and still pulls in reliably.
- One chip can drive all coils, including the external master-relay coil.

## Alternatives considered
- **Discrete logic-level MOSFETs** (IRLZ44N / AOD4184 / AO3400): viable, but needs separating
  the coil common (or high-side drivers) plus an external 1N4007 per coil. More parts for the
  same result.
- **High-side switching the white/85 lines** as the box is wired for: rejected — needs a
  high-side driver stage per channel.
- **Non-logic-level MOSFET boards (IRF540/IRF520)**: rejected — won't fully turn on at 3.3 V.

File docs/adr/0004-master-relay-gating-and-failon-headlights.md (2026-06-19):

# 4. External master relay gates the box; headlights stay outside it (fail-ON)

- Status: Accepted
- Date: 2026-06-19
- Deciders: Miki

## Context
The combo box has four fused relay outputs plus **two fuses (5 A and 30 A) that feed straight
out, bypassing the relays**. We want the whole box gated to the engine-running state, and we
need lighting that behaves safely if the controller fails.

## Decision
Feed the box's main 12 V through an **external, ESP-driven master relay** that closes only on
the engine-run signal. This hardware-gates the entire box and turns the 5 A / 30 A direct-outs
into **engine-switched** feeds. The **ESP draws its always-hot supply from its own battery tap
(inline 2 A fuse), upstream of the master relay**, so it outlives the relay for the off-delay
and parked sentinel. **Headlights stay OUTSIDE the gated box (fail-ON):** their relay coils are
triggered from the original start-button feed (relieving the starter switch and preserving the
factory cranking cut); one bulb is always-on, the second on a **5-pin NC relay** the ESP
energises only to shed in a critical low-power moment.

## Consequences
- Hardware engine-gate for the whole box → the four internal relays only do user on/off, no
  per-relay firmware engine check.
- The 5 A / 30 A direct-outs become useful switched feeds (e.g. tablet buck, a switched sub-bus).
- ESP power **must** be a separate battery tap, not the box.
- Fail-safe directions are deliberate: accessories **fail-OFF** (safe), headlights **fail-ON**
  (safe). Load-shed priority: grips → fog → (last, daylight only) one headlight; never all
  forward light.

## Alternatives considered
- **Firmware-only gating, per relay**: rejected — cannot gate the 5 A / 30 A direct-out fuses.
- **Headlights inside the gated box**: rejected — an ESP or master-relay fault would leave the
  bike dark; safety-critical lighting must never be solely behind the controller.

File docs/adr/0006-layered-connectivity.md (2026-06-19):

# 6. Layered connectivity: phone-relay BLE when parked, tablet radio when riding

- Status: Accepted
- Date: 2026-06-19
- Deciders: Miki

## Context
The bike lives in a **shared underground garage** — no WiFi, no reliable cellular, no fixed
position to phone home from — yet we want theft and battery telemetry while it's parked. The
owner and his wife pass the bike regularly on the way to the car.

## Decision
**Layer the connectivity** to the situation. **Riding:** the tablet's radio carries data
(including crash SMS). **Parked:** an **opportunistic BLE relay** — the bike queues events in
NVS and drains the queue through the owner's/wife's phones whenever they pass in range; no
bike-side radio needed in v1. **v2:** a dedicated LTE Cat-M / NB-IoT module + GPS + backup LiPo
for drive-away theft. The BLE GATT contract exposes Status / CrashFlag / EventRead / EventAck /
Config characteristics with a read → forward → ack drain, over an LE-bonded whitelist.

## Consequences
- No bike-side radio or data plan required for v1 — the phones are the radio.
- Works within the garage's hard constraints (no WiFi, no public position).
- Events persist in NVS until a phone relays them; nothing is lost between passes.
- The v2 LTE/GPS path is reserved without redesign.
- Parked liveness depends on a paired phone passing within BLE range.

## Alternatives considered
- **Bike-side WiFi in v1**: rejected — there is no garage WiFi to join.
- **Always-on LTE in v1**: deferred to v2 — cost, power draw, and complexity not justified yet.

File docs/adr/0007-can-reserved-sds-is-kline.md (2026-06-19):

# 7. CAN reserved for own modules; the bike's data is K-line SDS, not CAN

- Status: Accepted
- Date: 2026-06-19
- Deciders: Miki

## Context
We want future expansion (remote sensor/GPS/LTE nodes) and possibly to read the bike's own
engine data. The "fairings off once" philosophy means provisioning the harness now is far
cheaper than retrofitting later — so we need to know what the bike's data bus actually is.

## Decision
The **2013 DL650 has no CAN bus** — its data lives on **K-line SDS** (Suzuki Diagnostic System,
6-pin diagnostic connector). Therefore **CAN is reserved for our own module network**, not for
talking to the bike: ESP32 built-in TWAI controller + an **SN65HVD230** transceiver, a twisted
**CAN_H/CAN_L** pair as a linear backbone with **120 Ω at both ends** and node drops carrying
12 V + GND + CAN. To read bike data we interface the **SDS/K-line separately** (an Arduino-style
SDS reader) and may later bridge SDS → our CAN. Keep the diagnostic connector accessible.

## Consequences
- No expectation of "tapping CAN" for engine data — that path is K-line and a separate effort.
- Own CAN is provisioned now at near-zero cost: a transceiver footprint, two GPIOs, a twisted
  pair with end terminations, and node drops at likely locations (front, tail).
- A future SDS-to-CAN bridge can surface engine data on the dashboard without redesign.

## Alternatives considered
- **Assume the bike exposes CAN/OBD for data**: rejected — it does not; it's K-line SDS.
- **Skip CAN provisioning entirely**: rejected — retrofitting a backbone through the fairings
  later violates "fairings off once."

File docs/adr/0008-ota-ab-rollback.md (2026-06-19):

# 8. OTA with A/B rollback; bench-twin-first

- Status: Accepted
- Date: 2026-06-19
- Deciders: Miki

## Context
The bike-side ESP will be sealed and awkward to reach, so a bad firmware flash must never be
able to brick it. Two identical ESP32 units are on hand, which makes a disciplined test path
possible.

## Decision
Update over the air (**ArduinoOTA over WiFi**), with **A/B partition rollback** as the safety
layer: a new image self-validates after boot and the bootloader reverts to the previous slot if
it fails. Apply **bench-twin-first** discipline — every change is proven on the bench twin
before it touches the bike unit. One codebase builds both via two PlatformIO environments
(`bench` / `bike`), distinguished only by `DEVICE_NAME`.

## Consequences
- Wireless updates with no disassembly; identical, individually-addressable firmware on both units.
- A bad flash self-reverts instead of stranding a sealed controller.
- Regressions are caught on the bench before the bike ever sees them.
- On the bike, OTA happens when in WiFi range or via the tablet's hotspot.
- Requires the two-app-partition scheme (the default ESP32 table provides it) and the
  validate-or-revert logic (the next firmware milestone after basic OTA).

## Notes
Basic ArduinoOTA is proven working on the bench (USB-first flash, then wireless push). The
automatic rollback layer is the next milestone. A known Windows gotcha: OTA's reverse
connection fails behind extra network adapters (WSL/Hyper-V/VMware/VPN) and behind a
third-party AV firewall — disable the virtual adapters and the AV's network shield for the push.

## Alternatives considered
- **USB-only flashing**: rejected — the bike ESP is sealed and hard to reach.
- **OTA without rollback**: rejected — a single bad flash would brick a hard-to-reach unit.

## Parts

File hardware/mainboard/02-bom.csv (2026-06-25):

Ref | Qty | Value | Description | Footprint | Suggested part / MPN | Notes
A1 | 1 | ESP32-DevKitC | ESP32-WROOM-32D dev board (socketed) | 2x 1x19 female header 2.54mm | Espressif ESP32-DevKitC-32E | Reuse existing units; verify pin count/row pitch
A2 | 1 | IMU | 6-axis accel+gyro breakout (I2C) | 1x5 female header 2.54mm | ST LSM6DSO (pref) or InvenSense MPU-6050 | Wake-on-motion INT; LSM6DSO preferred
A3 | 1 | Buck | MP1584EN mini buck module | 4-pad 2.54mm | MP1584EN module | Pre-set 5.0V and verify before fitting
U2 | 1 | ULN2803A | Darlington array 8ch low-side | DIP-18 (socket) or SOIC-18 | Texas Instruments ULN2803A | Active-HIGH; COM to coil rail
U3 | 1 | INA3221 | 3-channel bus voltage/current monitor breakout (CJMCU-3221) | INA3221_Module (custom) | CJMCU-3221 purple module | CH1=bus voltage; CH2/3 spare; 26V input max (clamp D3); socket via labeled VS/GND/SCL/SDA/A0 row; confirm count/order
U4 | 1 | PC817 | Optocoupler single-channel | DIP-4 | Sharp PC817C | IGN 12V sense
U5 | 1 | PC817 | Optocoupler single-channel | DIP-4 | Sharp PC817C | START/headlight 12V sense
Q1 | 1 | P-MOSFET | Reverse-polarity protect | DPAK or TO-220 | AOD4185 / DMP3017SFG / IRF4905 | Source=+12V_HOT drain=+12V_PROT
D1 | 1 | SMBJ24A | TVS diode unidirectional 24V | SMB DO-214AA | Littelfuse SMBJ24A | Load-dump clamp on +12V_PROT
D2 | 1 | LED | Power indicator green | 3mm THT | generic | Optional
D3 | 1 | SMBJ20A | TVS diode unidirectional 20V | SMB DO-214AA | Littelfuse SMBJ20A | Clamp INA3221 sense input (26V limit)
Dz1 | 1 | 18V Zener | Gate-source clamp 0.5W | SOD-123 or THT | BZX84C18 / 1N5248B | >14.4V idle while charging; <20V Vgs(max)
C1 | 1 | 470uF/35V | Bulk electrolytic | radial 8mm | generic 105C | On +12V_PROT
C2 | 1 | 100uF/16V | Bulk electrolytic | radial 6.3mm | generic 105C | On +5V
C3 | 1 | 100nF | Decoupling X7R | 0805 or THT | generic | ESP power pin
C4 | 1 | 100nF | Decoupling X7R | 0805 or THT | generic | ULN2803
C5 | 1 | 100nF | Decoupling X7R | 0805 or THT | generic | INA3221
C6 | 1 | 100nF | Decoupling X7R | 0805 or THT | generic | PC817 U4/U5 area
C7 | 1 | 100nF | Decoupling X7R | 0805 or THT | generic | IMU
C8 | 1 | 100nF | Decoupling X7R | 0805 or THT | generic | spare/input
C9 | 1 | 10uF | Bulk X7R | 0805 or THT | generic | +3V3 near ESP
C10 | 1 | 1uF | RC filter | 0805 | generic | INA3221 VBUS sense filter
R1 | 1 | 10k | ULN input pulldown | 0805 or THT | generic | MASTER_EN
R2 | 1 | 10k | ULN input pulldown | 0805 or THT | generic | FOG_EN
R3 | 1 | 10k | ULN input pulldown | 0805 or THT | generic | GRIP_EN
R4 | 1 | 10k | ULN input pulldown | 0805 or THT | generic | SPARE_EN
R5 | 1 | 4.7k | I2C SDA pullup | 0805 | generic | to +3V3
R6 | 1 | 4.7k | I2C SCL pullup | 0805 | generic | to +3V3
R7 | 1 | 2.2k 0.25W | PC817 LED series | 1206 or THT | generic | IGN 12V side ~5mA
R8 | 1 | 2.2k 0.25W | PC817 LED series | 1206 or THT | generic | START 12V side ~5mA
R9 | 1 | 10k | GPIO34 pullup | 0805 | generic | opto output to +3V3
R10 | 1 | 10k | GPIO35 pullup | 0805 | generic | opto output to +3V3
R11 | 1 | 100k | Q1 gate-source | 0805 | generic | reverse-pol FET
R12 | 1 | 100R | Q1 gate series | 0805 | generic | optional slew limit
R13 | 1 | 220R | Power LED series | 0805 | generic | D2
R14 | 1 | 100R | INA3221 sense series | 0805 | generic | Light RC with C10; keep low to avoid bus-measure error
J1 | 1 | 2-pos 5.0mm | Terminal block | TerminalBlock_MaiXu_MX126-5.0-02P_1x02_P5.00mm | MX126-5.0 or any 2P 5.0/5.08mm | +12V_HOT / GND
J2 | 1 | 2-pos 5.0mm | Terminal block | TerminalBlock_MaiXu_MX126-5.0-02P_1x02_P5.00mm | MX126-5.0 or any 2P 5.0/5.08mm | COIL_RAIL / GND
J3 | 1 | 4-pos 5.0mm | Terminal block | TerminalBlock_MaiXu_MX126-5.0-04P_1x04_P5.00mm | MX126-5.0 or any 4P 5.0/5.08mm | Coil outputs to 85 wires
J4 | 1 | 3-pos 5.0mm | Terminal block | TerminalBlock_MaiXu_MX126-5.0-03P_1x03_P5.00mm | MX126-5.0 or any 3P 5.0/5.08mm | IGN_12V / START_12V / SENSE_GND
J5 | 1 | 2-pos 5.0mm | Terminal block | TerminalBlock_MaiXu_MX126-5.0-02P_1x02_P5.00mm | MX126-5.0 or any 2P 5.0/5.08mm | INA3221 VBUS_SENSE / GND
J6 | 1 | 1x4 header | I2C expansion | 2.54mm THT | generic | +3V3 SDA SCL GND
J7 | 1 | 2x4 header | ULN spare ch5-8 breakout | 2.54mm THT | generic | future relays
J8 | 1 | 1x9 JST-XH | Handlebar aux buttons connector | Connector_JST:JST_XH_B9B-XH-A_1x09_P2.50mm_Vertical | JST B9B-XH-A | BTN1..8 + common GND (ADR-0014)
R15 | 1 | 1k | Button series (RC) | 0805 or THT | generic | BTN1; omit on bench
R16 | 1 | 1k | Button series (RC) | 0805 or THT | generic | BTN2; omit on bench
R17 | 1 | 1k | Button series (RC) | 0805 or THT | generic | BTN3; omit on bench
R18 | 1 | 1k | Button series (RC) | 0805 or THT | generic | BTN4; omit on bench
R19 | 1 | 1k | Button series (RC) | 0805 or THT | generic | BTN5; omit on bench
R20 | 1 | 1k | Button series (RC) | 0805 or THT | generic | BTN6; omit on bench
R21 | 1 | 1k | Button series (RC) | 0805 or THT | generic | BTN7; omit on bench
R22 | 1 | 1k | Button series (RC) | 0805 or THT | generic | BTN8; omit on bench
C11 | 1 | 100nF | Button RC to GND | 0805 or THT | generic | BTN1
C12 | 1 | 100nF | Button RC to GND | 0805 or THT | generic | BTN2
C13 | 1 | 100nF | Button RC to GND | 0805 or THT | generic | BTN3
C14 | 1 | 100nF | Button RC to GND | 0805 or THT | generic | BTN4
C15 | 1 | 100nF | Button RC to GND | 0805 or THT | generic | BTN5
C16 | 1 | 100nF | Button RC to GND | 0805 or THT | generic | BTN6
C17 | 1 | 100nF | Button RC to GND | 0805 or THT | generic | BTN7
C18 | 1 | 100nF | Button RC to GND | 0805 or THT | generic | BTN8
TP1 | 1 | Testpoint | +12V_PROT | THT loop | generic
TP2 | 1 | Testpoint | +5V | THT loop | generic
TP3 | 1 | Testpoint | +3V3 | THT loop | generic
TP4 | 1 | Testpoint | GND | THT loop | generic

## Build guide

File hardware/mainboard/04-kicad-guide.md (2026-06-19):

<!-- SPDX-License-Identifier: CERN-OHL-P-2.0 -->
# Mainboard — KiCad capture & layout, step by step

How to turn [01-schematic-spec.md](01-schematic-spec.md) into a KiCad 10 schematic + routed PCB +
fab files (steps are stable across KiCad 8–10). I (Claude) can't drive the GUI, so this is the hands-on part — but every value,
connection, and rule is pinned down in the spec, BOM, and design rules so you're transcribing,
not deciding. Ping me at any step (DRC errors, footprint questions, a net you're unsure of).

> **Before you start:** install the **current stable KiCad 10.x** (Windows) from
> <https://www.kicad.org/download/>. Then tell me — I'll note it in `hardware/README.md`.

---

## 1. Create the project
1. KiCad → **File → New Project** → save as `hardware/mainboard/mainboard.kicad_pro`.
   (Keep it inside the repo so it's version-controlled. The `hardware/.gitignore` already
   excludes KiCad backup/cache cruft.)
2. Open the **Schematic Editor**.

## 2. Pull in symbol libraries
Most parts are in KiCad's built-in libs. You'll need a few module symbols:
- **ESP32-DevKitC**: built-in `RF_Module:ESP32-DEVKITC-32D` (or `ESP32-WROOM-32`). If you prefer
  the socketed-header approach, you can instead place two `Connector_Generic:Conn_01x19` and
  label nets by GPIO — but the DevKitC symbol is cleaner; just assign a **female-header
  footprint** to it in step 4.
- **ULN2803A**: `Driver_Relay:ULN2803A` (or `Relay:ULN2803A`).
- **INA3221 (module)**: place as `Connector_Generic:Conn_01x04` labelled `VS/GND/SDA/SCL`, plus a
  channel input (CH1) for the sense lead. (A stock symbol may exist, but the module-as-connector
  approach keeps it simple.) Note: INA3221, not INA226 — see ADR-0011.
- **MP1584 buck**: no stock symbol — place `Connector_Generic:Conn_01x04`, label `IN+ IN− OUT+ OUT−`.
- **IMU (LSM6DSO/MPU-6050)**: place `Connector_Generic:Conn_01x05`, label `VCC GND SDA SCL INT`.
- **PC817**: `Isolator:PC817`.
- **Passives / Q1 / TVS / Zener / LED / caps**: `Device` library (R, C, CP, D, D_Zener, D_TVS,
  Q_PMOS_GSD, LED).
- **Terminal blocks / headers**: `Connector` / `Connector_Generic`.

> Treating the breakout boards as connectors (with net labels) is the standard, low-friction way
> to put modules on a carrier — it keeps the schematic readable and the footprint is just a
> header.

## 3. Capture the schematic (from the spec)
Work block by block — the spec is already grouped this way. For each:
1. Place the symbols for that block.
2. Wire them, or (faster for a net-heavy board) use **global labels** with the exact net names
   from the spec (`+12V_PROT`, `COIL_RAIL`, `SDA`, `IGN_SENSE`, …). Matching labels = connected.
3. Set values and reference designators to **match the BOM exactly** (`R1`=10k, etc.).

Recommended order (mirrors the spec):
1. **Power in**: J1 → Q1 (reverse-pol) → D1 (TVS) → C1 → A3 buck → +5V → A1 5V/VIN. Add R11/R12/Dz1.
2. **ESP A1**: drop the DevKitC, label its GPIOs per the *pin usage* table.
3. **ULN U2**: in1–4 from GPIO 13/25/26/27 with R1–R4 pulldowns; out1–4 → J3; COM→COIL_RAIL (J2); GND. Break ch5–8 to J7.
4. **I²C**: SDA/SCL from A1.21/22 to U3 + A2, R5/R6 pull-ups, J6. IMU INT→A1.33. INA3221 CH1 sense J5→R14→U3, C10, D3 clamp.
5. **Opto**: U4 (IGN) and U5 (START) per the table — R7/R8 on 12 V side, R9/R10 pull-ups, J4.
6. **Indicator + test points + decoupling caps** (one 100 nF per IC).
7. Run **Inspect → Electrical Rules Checker (ERC)**. Fix every error (un-driven nets, missing
   power flags — add `PWR_FLAG` on +12V_HOT, +5V, +3V3, GND, COIL_RAIL).

**Cross-check against the spec's net table when ERC is clean** — confirm each net lists the same
pins. Send me the netlist or a screenshot and I'll diff it against the spec.

## 4. Assign footprints
Tools → **Assign Footprints**. Use the footprints column in [02-bom.csv](02-bom.csv):
- A1 → female-header footprint matching your DevKitC (two `PinSocket_1x19_P2.54mm` rows; **measure
  your board's row spacing** — common is 0.9″ or 1.0″).
- A2/U3/A3/J6/J7 → `PinSocket`/`PinHeader` 2.54 mm of the right pin count.
- U2 → `DIP-18_W7.62mm` (+ socket) or `SOIC-18`.
- U4/U5 → `DIP-4`. Q1 → `TO-252`/`TO-220`. Passives → `0805` (or THT `Resistor_THT` if you prefer hand-soldering).
- J1/J2 → `TerminalBlock_5.08mm` 2-pos; J3/J4/J5 → `TerminalBlock_3.5mm` of the right size.

## 5. Lay out the PCB
1. Schematic Editor → **Tools → Update PCB from Schematic** (pushes netlist + footprints).
2. Set board rules from [03-design-rules.md](03-design-rules.md): **File → Board Setup → Design
   Rules / Net Classes**. Make net classes **Power** (1.5 mm), **Rail3V3** (0.8 mm), **Default/
   Signal** (0.30 mm); clearance 0.2 mm; via 0.4/0.8.
3. **Placement** (do this well — it's 80% of a good board):
   - DevKitC along one edge, **antenna end overhanging** (antenna keep-out, no copper).
   - Terminal blocks J1–J5 along the opposite/adjacent **field-wiring edge**.
   - Buck A3 near J1 (power entry); keep its loop tight.
   - ULN U2 between the ESP GPIO side and J3.
   - Opto U4/U5 straddling the 12 V edge (J4) with the **4 mm isolation gap** kept clear.
   - INA226/IMU on the I²C side, sense lead (J5) short.
4. Draw the **board outline** (Edge.Cuts) ~90 × 70 mm; add 4× M3 holes.
5. **Route**: power nets first (1.5 mm), then signals. Pour **GND** on both layers; stitch with
   vias. Keep I²C away from the buck switch node; don't pour under the opto barrier.
6. **DRC** (Inspect → Design Rules Checker) until zero errors. Send me the DRC report if stuck.

## 6. Review against fail-safe rules
Before fab, confirm:
- ULN input pulldowns present → relays **OFF at boot** (fail-OFF). ✔
- No external flyback diodes (ULN COM→COIL_RAIL). ✔
- GPIO34/35 pull-ups present (input-only pins). ✔
- Opto isolation gap intact; 12 V kept off the logic side. ✔
- Antenna keep-out clear. ✔

## 7. Fabrication outputs
- **File → Plot** → Gerbers (all copper, mask, silk, Edge.Cuts) → `gerbers/` (gitignored by
  default; un-ignore if you want to tag a release).
- **File → Fabrication Outputs → Drill Files**.
- Zip the Gerbers + drill → upload to JLCPCB/PCBWay. 2-layer, 1.6 mm, HASL, default rules.
- (Optional) Export **BOM** + **centroid** if you ever want assembly; for hand-build, skip.

## 8. After boards arrive
- Hand-assemble, then run the **[bench relay guide](../../docs/bench-relay-guide.html)** against
  the real board: `selftest` should click the coils through the ULN; verify GPIO 13/25/26/27,
  the 5 V/3V3 rails (TP2/TP3), and opto inversion (12 V on IGN_12V → GPIO34 reads LOW).
- Record any rework as a v1.1 note here, and promote firm changes to an ADR.

---

### Where I can plug in
Send me: the ERC/DRC report, a netlist export, a placement screenshot, or any "which footprint /
is this net right?" question. I'll check it against the spec and the fail-safe rules and tell you
exactly what to change.

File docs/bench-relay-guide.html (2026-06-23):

moto-11 / Bench relay guide

# Driving the relays before the bike

Get the relay-control firmware onto an ESP32 and click the relays on the bench — before anything is installed on the motorcycle.

This is firmware (https://github.com/mixajlo/moto-11/tree/main/firmware) Milestone 2 in practice: a RelayController that owns the four ULN2803-driven coil enables, plus a hand-driven serial/Telnet console to actuate them. It assumes nothing about the bike — you can do all of this with just an ESP32 dev board on a USB cable, and add the relay box later. Physical, hands-on steps (probing pins, listening for clicks, all wiring) are yours; everything else runs from the firmware.

▶ Why bench-first The project rule is “every change is proven on the bench twin before it touches the bike.” This guide is that proof step for relay control.

## 0What you need

Minimum (logic only):

- An ESP32 dev board (this project targets ESP32-WROOM-32D) and a USB cable.
- A PC with VS Code (https://code.visualstudio.com/) + the PlatformIO IDE extension.
- The Silicon Labs CP210x USB-to-UART driver — the boards use a CP2102, and without the driver Windows shows no COM port.

To see real relays move (optional, add when ready):

- The pre-wired 4-relay / 6-fuse box.
- A ULN2803A Darlington array (the coil driver — see ADR-0003 (https://github.com/mixajlo/moto-11/blob/main/docs/adr/0003-uln2803-coil-driver.md)).
- A bench 12 V supply for the coil rail.
- A multimeter, and optionally a 3.3 V LED + resistor to watch a single channel.

## 1Get the firmware and configure secrets

Open the firmware/ folder directly in VS Code (PlatformIO expects platformio.ini at the root of the opened folder — open firmware/, not the repo root). Copy the secrets template and fill it in (it’s gitignored, so your credentials never reach the repo):

cp include/secrets.h.example include/secrets.h

Set WIFI_SSID, WIFI_PASS, and an OTA_PASS. WiFi is optional for the bench — the relay console runs over USB whether or not WiFi connects — but valid credentials also give you the Telnet console and wireless (OTA) updates. The OTA_PASS must match the --auth= value in platformio.ini. Avoid % and $ in the OTA password (the config parser treats them specially).

## 2Build and flash over USB

Plug the board in. From the firmware/ directory:

pio run -e bench                 # compile
pio run -e bench -t upload       # flash over USB (auto-detects the port)

If PlatformIO picks the wrong port, name it explicitly — find the COM port in Windows Device Manager under Ports (COM & LPT) (it shows as Silicon Labs CP210x):

pio run -e bench -t upload --upload-port COM4

A successful flash ends with Hard resetting via RTS pin... and [SUCCESS].

▶ Second unit The bike ESP uses the same code — swap bench → bike. The only difference is DEVICE_NAME, set per environment in platformio.ini.

## 3Open the console

pio device monitor               # 115200 baud

On boot you should see something like:

=== vstrom-bench booting ===
WiFi: connecting to "your-wifi" in the background...

=== moto-11 bench relay console ===
  status | s        show every channel + GPIO + state
  on   <ch|all>      energise a channel (relay pulls in)
  off  <ch|all>      de-energise a channel
  toggle <ch>        flip a channel
  selftest           click each relay in turn (300ms each)
  help | ?           this list
  channels: master  fog  grip  spare
(onboard LED: heartbeat when all off, solid ON when any relay is on)
Bench relay console live on USB serial. Type 'help'.
WiFi OK   IP 192.168.0.104   host vstrom-bench.local — OTA + telnet console live

The console works immediately on USB. If WiFi connects, the last line appears and you also get the same console over Telnet (port 23) at the shown IP or vstrom-bench.local.

## 4Drive the relays

Type commands and press Enter:

Command | Effect
status (or s) | List every channel, its GPIO, and ON/off state
on fog | Energise the fog channel (GPIO goes HIGH → relay pulls in)
off fog | De-energise it
toggle grip | Flip the grip channel
on all / off all | Energise / de-energise all four
selftest | Click each relay in turn — master, fog, grip, spare — 300 ms each, then all off
help (or ?) | Reprint the command list

The four logical channels and their pins (full rationale in ADR-0009 (https://github.com/mixajlo/moto-11/blob/main/docs/adr/0009-gpio-pin-map.md)):

Channel | GPIO | Drives
master | 13 | External master relay — gates the whole box
fog | 25 | Fog lights
grip | 26 | Heated grips (future load)
spare | 27 | Reserved aux channel

## 5Confirm it actually works (your hands)

A firmware “upload OK” is not proof a relay moved. Confirm physically — pick the level of hardware you have on the bench:

### A. ESP board only (no ULN/relay box yet)

The channels are real 3.3 V logic outputs but drive nothing visible. Two checks:

- Onboard LED: idle shows a ~1 Hz heartbeat. Type on master → the LED goes solid; off all → the heartbeat returns. That proves the control logic runs.
- Multimeter on the pin: black probe to GND, red probe to GPIO 13 / 25 / 26 / 27. It should read ~3.3 V when that channel is ON and ~0 V when off. (Optionally put a 3.3 V LED + ~330 Ω resistor from the pin to GND to watch one channel.)

### B. ULN2803 wired, no relay box

Wire ULN inputs 1–4 to GPIO 13/25/26/27 in that order, ULN GND (pin 9) to the ESP GND. With a channel ON, the matching ULN output sinks to ~0 V (it’s an open-collector low-side switch); off, it floats. Confirm with the multimeter.

### C. Full chain (ULN + relay box + 12 V)

Connect per the wiring schematic ULN2803 detail: the box’s commoned pin 86 is the +12 V coil rail, ULN COM (pin 10) → +12 (internal flyback), each white pin-85 coil wire sunk by one ULN output. Now each on <channel> should produce an audible relay click, and selftest clicks all four in sequence. Verify continuity across the relay’s switched contacts (30↔87) closes when energised.

⚠ Fail-safe to expect Every relay is OFF at boot and stays off until you command it — by design. Accessories are fail-OFF (ESP dead → loads dark, which is safe). If a relay energises on its own at power-up, stop and check your wiring against ADR-0003 (https://github.com/mixajlo/moto-11/blob/main/docs/adr/0003-uln2803-coil-driver.md)/0009 (https://github.com/mixajlo/moto-11/blob/main/docs/adr/0009-gpio-pin-map.md).

## 6Update wirelessly (OTA) — optional

Once the board is on WiFi and you’ve flashed it once over USB, you can update it without the cable:

pio run -e bench_ota -t upload

Set the device’s IP (from the boot log) as upload_port in the bench_ota environment if the .local mDNS name doesn’t resolve on your OS. OTA forces all relays off before it writes, so an interrupted flash can’t leave a coil energised. Windows OTA gotchas (extra network adapters, third-party AV firewalls) are covered in the README (https://github.com/mixajlo/moto-11#ota-updates) and ADR-0008 (https://github.com/mixajlo/moto-11/blob/main/docs/adr/0008-ota-ab-rollback.md).

## 7Troubleshooting

Symptom | Likely cause / fix
No COM port appears | CP210x driver not installed, or a charge-only USB cable.
pio can’t find the project | You opened the repo root — open firmware/ (where platformio.ini lives).
Console prints nothing | Wrong baud — set the monitor to 115200. Press Enter; type help.
WiFi line never appears | Bad/blank credentials in secrets.h. The USB console still works — WiFi is optional on the bench.
LED heartbeats but no relay click | (Full chain) check ULN COM→+12, the coil +12 rail (pin 86), and ULN GND; confirm inputs land on 13/25/26/27.
A relay is on at power-up | Wiring fault — relays must be fail-OFF. Recheck against ADR-0003 and the pull-downs on the ULN inputs.

## 8Where this fits

This is the manual, hands-on layer. On top of it runs the autonomous engine-run supervisor — SLEEP → ARMED → RUNNING ↔ POWERED (+ OFF_DELAY), the state machine in the electrical plan §13 / ADR-0012 — which drives this exact same RelayController. It's already implemented and bench-tested with simulated sensors (console: sim ign / sim vbus, state); the remaining milestone is the real INA3221 + PC817 sensing front-end (then sim real) and load-shedding. The bench console stays as a diagnostic tool underneath it.

Part of the moto-11 documentation. Source and decision records are on GitHub (https://github.com/mixajlo/moto-11). Licensed CC-BY-4.0 (https://creativecommons.org/licenses/by/4.0/).

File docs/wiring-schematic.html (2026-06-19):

# DL650 Smart Cockpit — Wiring Schematic

Accessible build sheet. Every wire type has a distinct line pattern + text tag, so it never depends on telling colours apart. The wire schedule below is the colour-free master key.

SHEET 1/1 · REV B
colourblind-safe encoding

+12V solid · thick · battery (always hot)

SW solid · medium · switched accessory

GND solid · black · ground (star)

SIG dashed · logic / sense / gate

I2C dotted · sensor bus

BLE dash-dot · wireless (no wire)

Reading this if colours are hard to separate: go by the line pattern first — solid-thick = +12V, solid-medium = switched, solid-black = ground, dashed = logic/sense, dotted = I²C, dash-dot = wireless. Every wire also carries a short tag (+12V / SW / GND / SIG / I2C) and a W-number that you can look up in the wire schedule, which states the type in words.

## Detail — ULN2803A coil driver

How the ESP drives the four relay-box coils: the commoned pin 86 is reused as the +12 V coil rail, each white/85 wire is low-side sunk by one ULN2803 channel, and flyback is handled inside the chip — so no external 1N4007s on the box.

## Wire Schedule — the colour-free master key

Ref | Pattern | From → To | Gauge | Fuse
W1/W2 | +12V solid | Battery + → main fuse → +12V dist rail | 12 AWG | 25 A
W3 | +12V solid | +12V rail → relay pin 30 | 12 AWG | (main)
W4 | +12V solid | +12V rail → relay pin 85 (coil +) | 18 AWG | —
W5 | +12V solid | +12V rail → 2A → rev-pol → TVS/cap → buck → ESP 5V | 18→20 AWG | 2 A
W6 | SW solid | Relay pin 87 → switched acc bus | 12 AWG | per-load
W7 | SIG dashed | Relay pin 86 → relay-drive FET → GND (flyback = W7b) | 18 AWG | —
W8 | SW solid | Switched bus → 7.5A → fog relay → fog lights → GND. ESP FOG_EN (SIG) drives coil. v1 on/off; v2 → MOSFET PWM | 16 AWG | 7.5 A
W9 | SW solid | Switched bus → 7.5A → grip relay → heated grips → GND (future). ESP GRIP_EN drives coil. v1 on/off; v2 → MOSFET PWM | 16 AWG | 7.5 A
W10 | SW solid | Switched bus → 5A → PD buck → spine → tablet | 18 AWG | 5 A
W11 | SW solid | Switched bus → 7.5A → spare (capped) | 16 AWG | 7.5 A
W12 | SIG dashed | Keyed-fuse tap → divider/Zener → ESP IGN_SENSE | 22 AWG | (tap)
W13 | SW + GND | Spine: SW12V + GND + spare pair + 2× shielded signal | 18/22 AWG | —
W14 | GND solid | Battery − → ground star bus (single return) | 12 AWG | —
I2C | I2C dotted | ESP SDA/SCL ↔ INA226 + IMU | 22–24 AWG | —

v1 control = your mechanical relay box (on/off only). The ESP drives each coil through a ULN2803A Darlington array (see detail above): the box's commoned pin 86 becomes the +12 V coil rail, each white/85 wire is low-side sunk by one channel, and the chip's COM→+12 internal clamp diodes handle flyback — so no 1N4007s on the box. FOG_EN and GRIP_EN are simple on/off enables, not PWM, and active-high (GPIO high → relay on). The external master relay gates the whole box on the engine-running logic. v2 upgrade: swap a load's relay for a logic-level MOSFET on the same enable line to gain PWM dimming — same wiring, same ESP pin, only the switching element changes.

Build order on the bike: battery − off first → mount ground bus, relay box, ESP enclosure → run + label the spine and set service loops → main fuse on battery + → build & bench-verify the ESP buck (5.0 V) before connecting the ESP → land the master-relay coil + flyback → wire each load relay (coil ← ESP enable, contact passes fused +12V to the load) → all grounds to the star → reconnect & bench-test the engine-running logic with a variable supply before fairings go back on.

Reserve for v2 (so fairings stay on): leave one spine pair unused, route an antenna path forward, and leave bay volume near the ESP for the LTE + GPS + backup-LiPo board. The relay drive, I²C bus, and ground star already accommodate it — v2 is additive, not a rewire.

DL650 Smart Cockpit · Wiring Schematic Rev B (colourblind-safe) · Companion to the full Electrical Plan. Wire types encoded by pattern + tag, not colour alone. Symbols simplified for build planning, not certification. Confirm the keyed-fuse choice, relay pinout, and real load currents on your bike before final fusing.

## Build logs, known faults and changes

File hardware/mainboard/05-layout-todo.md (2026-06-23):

<!-- SPDX-License-Identifier: CERN-OHL-P-2.0 -->
# Mainboard — PCB layout refine checklist

Tracking list for the layout pass. The first placement is a **guesstimate** (done before all
hardware is in hand) just to validate size/shape. Work through this before generating fab files.
See [03-design-rules.md](03-design-rules.md) for the numbers and [04-kicad-guide.md](04-kicad-guide.md)
for the how-to.

## Board strategy / phasing (decided 2026-06)
- **Now:** bench-validate the design using through-hole parts / modules / the existing
  ESP + relay box. No PCB ordered yet.
- **Before fab:** lock the **form factor against the real mounting location** — the current
  rectangular outline is a *reference prototype* only; final shape is TBD (likely non-rectangular).
- **Production board:** redesign as **SMD**, with parts chosen from the assembler's catalog
  (JLCPCB/LCSC, prefer "basic" parts), and **manufacturer-assembled (PCBA)** so there are no
  parts to hand-source/solder. The **schematic/netlist carries over** — only footprints
  (THT→SMD) and the outline change.

## Placeholders to replace (put in for the rough pass)
- [ ] **U3 (INA3221)** — currently `PinSocket_1x06` placeholder. Replace with the real custom
  footprint once measured (header pin count + 2.54 mm pitch + CH1 hole-pair spacing). Goes in
  `mainboard.pretty` alongside `MP1584_Module`.
- [ ] **Q1 (P-FET)** — currently `TO-220-3_Vertical` placeholder. Confirm once the FET is ordered
  (suggested **IRF4905**). Its pinout is **G-D-S**, so switch the symbol to `Q_PMOS_GDS` and
  re-verify pad mapping (D→+12V_HOT, S→+12V_PROT).
- [ ] **A3 (MP1584)** — custom `MP1584_Module` footprint done; **verify pad order against the
  physical board** at assembly (pad 1 = IN+, pad 3 = OUT+).

## Decisions still open
- [x] **Opto**: resolved — **bare PC817 DIP-4, integrated** (current design). Buy new chips;
  the 2-channel module stays whole as a bench tool. (Production board uses an SMD opto.)
- [ ] Confirm **MP1584 / INA3221 / IMU** module pin orders vs their silkscreens.

## Board setup (Board Setup → Design Rules / Net Classes)
- [ ] Net classes: **Power** (`+12V_HOT/PROT`, `+5V`, `COIL_*`, `COIL_RAIL`) = **1.5 mm**;
  **Rail3V3** (`+3V3`) = **0.8 mm**; **Default/signal** = **0.30 mm**.
- [ ] Clearance **0.2 mm**; via 0.4/0.8 mm.

## Placement / mechanical
- [ ] DevKitC (J8/J9) along one edge, **antenna end overhanging** — copper keep-out under the
  WROOM antenna, any layer.
- [ ] **USB end of the DevKitC reachable** for reflashing (orient to a board edge).
- [ ] Terminal blocks J1–J5 on the **field-wiring edge**, one side.
- [ ] Buck loop tight; INA3221 sense (`R14`/`C10`/`D3`) short, away from the buck switch node.
- [ ] **Opto isolation gap ≥ 4 mm** across U4/U5; **no ground pour under the opto barrier**.
- [ ] 4× **M3 mounting holes**, ~4 mm from corners.
- [ ] Resize **Edge.Cuts** to the real outline once placement settles (~90 × 70 mm guess).

## Routing
- [ ] Route **power nets first** (1.5 mm), then signals (0.3 mm).
- [ ] **GND pour both layers**, stitched with vias (~10 mm grid + around the ESP/RF area).
- [ ] Keep I²C as a pair, away from the buck.

## Verify before fab
- [ ] **DRC** clean (Inspect → Design Rules Checker).
- [ ] Re-check fail-safe: ULN input pull-downs, no external flyback (COM→COIL_RAIL), GPIO34/35
  pull-ups, antenna keep-out, opto barrier intact.
- [ ] **Plot Gerbers** + drill (`File → Plot`, `File → Fabrication Outputs`) → zip → JLCPCB
  (2-layer, 1.6 mm, HASL). Outputs go to `gerbers/` (gitignored).

## After boards arrive
- [ ] Hand-assemble, then run the [bench relay guide](../../docs/bench-relay-guide.html) against
  the real board (relay clicks via ULN, 5 V/3V3 rails at test points, opto inversion).
- [ ] Fold any rework into a v1.1 note here; promote firm changes to an ADR.

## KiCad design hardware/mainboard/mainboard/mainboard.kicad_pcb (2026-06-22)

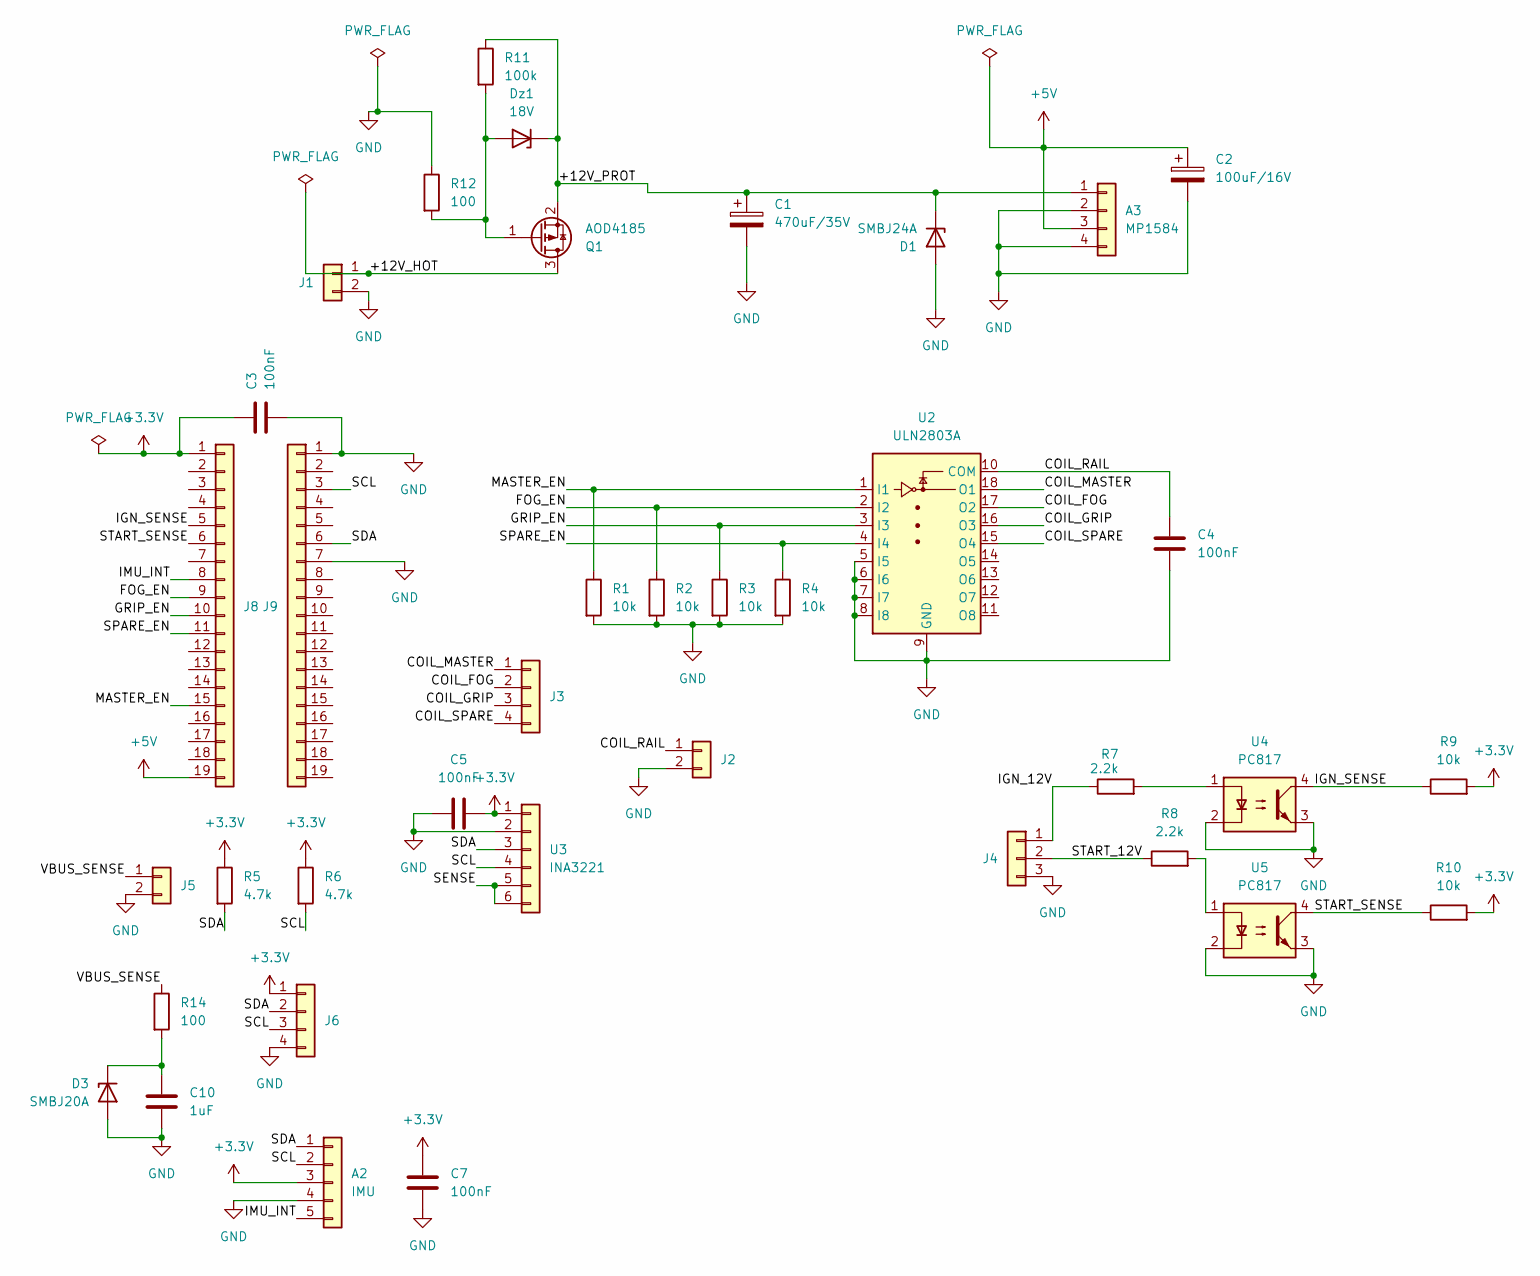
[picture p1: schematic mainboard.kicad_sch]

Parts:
A2: IMU; PinSocket_1x05_P2.54mm_Vertical
A3: MP1584; MP1584_Module
C1: 470uF/35V; CP_Radial_D8.0mm_P3.50mm
C2: 100uF/16V; CP_Radial_D6.3mm_P2.50mm
C3, C4, C5, C7: 100nF; C_Disc_D5.0mm_W2.5mm_P5.00mm
C10: 1uF; C_Disc_D5.0mm_W2.5mm_P5.00mm
D1: SMBJ24A; D_SMB
D3: SMBJ20A; D_SMB
Dz1: 18V; D_DO-35_SOD27_P7.62mm_Horizontal
J1, J5: TerminalBlock_MaiXu_MX126-5.0-02P_1x02_P5.00mm
J2: Conn_01x02; TerminalBlock_MaiXu_MX126-5.0-02P_1x02_P5.00mm
J3: Conn_01x04; TerminalBlock_MaiXu_MX126-5.0-04P_1x04_P5.00mm
J4: TerminalBlock_MaiXu_MX126-5.0-03P_1x03_P5.00mm
J6: PinHeader_1x04_P2.54mm_Vertical
J8, J9: ESP32; PinSocket_1x19_P2.54mm_Vertical
Q1: AOD4185; TO-220-3_Vertical
R1, R2, R3, R4, R9, R10: 10k; R_Axial_DIN0207_L6.3mm_D2.5mm_P7.62mm_Horizontal
R5, R6: 4.7k; R_Axial_DIN0207_L6.3mm_D2.5mm_P7.62mm_Horizontal
R7, R8: 2.2k; R_Axial_DIN0207_L6.3mm_D2.5mm_P7.62mm_Horizontal
R11: 100k; R_Axial_DIN0207_L6.3mm_D2.5mm_P7.62mm_Horizontal
R12, R14: 100; R_Axial_DIN0207_L6.3mm_D2.5mm_P7.62mm_Horizontal
U2: ULN2803A; DIP-18_W7.62mm_Socket
U3: INA3221; PinSocket_1x06_P2.54mm_Vertical
U4, U5: PC817; DIP-4_W7.62mm

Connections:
+3.3V: A2.3, C3.1, C5.2, C7.1, J6.1, J8.1, R5.1, R6.1, R9.2, R10.2, U3.1
+5V: A3.3, C2.1, J8.19
/+12V_HOT: J1.1, Q1.3 (D)
/+12V_PROT: A3.1, C1.1, D1.1 (K), Dz1.1 (K), Q1.2 (S), R11.1
/COIL_FOG: J3.2, U2.17 (O2)
/COIL_GRIP: J3.3, U2.16 (O3)
/COIL_MASTER: J3.1, U2.18 (O1)
/COIL_RAIL: C4.1, J2.1, U2.10 (COM)
/COIL_SPARE: J3.4, U2.15 (O4)
/FOG_EN: J8.9, R2.1, U2.2 (I2)
/GRIP_EN: J8.10, R3.1, U2.3 (I3)
/IGN_12V: J4.1, R7.1
/IGN_SENSE: J8.5, R9.1, U4.4
/IMU_INT: A2.5, J8.8
/MASTER_EN: J8.15, R1.1, U2.1 (I1)
/SCL: A2.2, J6.3, J9.3, R6.2, U3.4
/SDA: A2.1, J6.2, J9.6, R5.2, U3.3
/SENSE: U3.5, U3.6
/SPARE_EN: J8.11, R4.1, U2.4 (I4)
/START_12V: J4.2, R8.1
/START_SENSE: J8.6, R10.1, U5.4
/VBUS_SENSE: J5.1, R14.1
GND: A2.4, A3.2, A3.4, C1.2, C2.2, C3.2, C4.2, C5.1, C7.2, C10.2, D1.2 (A), D3.2 (A), J1.2, J2.2, J4.3, J5.2, J6.4, J9.1, J9.7, R1.2, R2.2, R3.2, R4.2, R12.1, U2.5 (I5), U2.6 (I6), U2.7 (I7), U2.8 (I8), U2.9 (GND), U3.2, U4.2, U4.3, U5.2, U5.3
unnamed: C10.1, D3.1 (K), R14.2
unnamed: Dz1.2 (A), Q1.1 (G), R11.2, R12.2
unnamed: R7.2, U4.1
unnamed: R8.2, U5.1

Board: 2 copper layers, 38 parts (0 on the bottom side), 27 nets, no tracks yet.

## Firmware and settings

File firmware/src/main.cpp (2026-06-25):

// ===== V-Strom Smart Cockpit — firmware =====
// Milestone 3: autonomous engine-run supervisor (SLEEP/ARMED/RUNNING/OFF_DELAY)
// on top of the relay control.
//   - RelayController owns the four ULN2803-driven coil enables (fail-OFF).
//   - Sensors provides bus voltage + ignition (bench SIM until INA3221/opto wired).
//   - Supervisor drives the MASTER relay off the engine-run signal.
//   - Serial/Telnet console drives relays AND injects fake sim inputs for bench.
//   - WiFi + ArduinoOTA + heartbeat carry over from earlier milestones.
// Same code on both ESPs; DEVICE_NAME comes from the build environment.

#include <Arduino.h>
#include <WiFi.h>
#include <ESPmDNS.h>
#include <ArduinoOTA.h>
#include <TelnetStream.h>

#include "secrets.h"
#include "pins.h"
#include "relays.h"
#include "console.h"
#include "sensors.h"
#include "supervisor.h"
#include "config.h"
#include "buttons.h"

#ifndef DEVICE_NAME
#define DEVICE_NAME "vstrom-esp"   // fallback if no build flag is set
#endif

// The live firmware (setup/loop + WiFi/OTA) is excluded from unit-test builds —
// `pio test` provides its own runner. PIO_UNIT_TESTING is defined during tests.
#ifndef PIO_UNIT_TESTING

uint32_t lastBlink  = 0;
bool      ledOn      = false;
bool      netUp      = false;   // true once WiFi+OTA+telnet are live
uint32_t  lastWifiTry = 0;

void setupOTA() {
  ArduinoOTA.setHostname(DEVICE_NAME);
  ArduinoOTA.setPassword(OTA_PASS);

  // Force relays OFF before a flash so a half-written image can't leave a coil
  // energised, and so the box is in a known state on reboot.
  ArduinoOTA.onStart([]() { Relays.allOff(); Serial.println("\n[OTA] update starting"); });
  ArduinoOTA.onEnd([]()   { Serial.println("\n[OTA] done — rebooting"); });
  ArduinoOTA.onProgress([](unsigned int p, unsigned int t) {
    Serial.printf("[OTA] %u%%\r", (p * 100) / t);
  });
  ArduinoOTA.onError([](ota_error_t e) {
    Serial.printf("\n[OTA] error %u\n", e);
  });
  ArduinoOTA.begin();
}

// Bring up the services that need an IP. Called once WiFi first associates.
void startNetServices() {
  TelnetStream.begin();
  setupOTA();
  netUp = true;
  Serial.printf("WiFi OK   IP %s   host %s.local — OTA + telnet console live\n",
                WiFi.localIP().toString().c_str(), DEVICE_NAME);
}

void setup() {
  Serial.begin(115200);

  // Relays first: get every coil enable driven LOW before anything else can
  // block. Accessories are fail-OFF, so this is the safest possible boot state.
  Relays.begin();
  Sensor.begin();
  Engine.begin();
  Cfg.begin();      // overlay NVS-saved tunables onto the supervisor defaults
  Btns.begin();     // handlebar aux buttons (INPUT_PULLUP, fail to "not pressed")

  pinMode(PIN_LED, OUTPUT);
  delay(300);
  Serial.printf("\n\n=== %s booting ===\n", DEVICE_NAME);

  // Non-blocking: kick off the association and move on. The relay console runs
  // over USB serial whether or not WiFi ever comes up — essential on the bench.
  WiFi.mode(WIFI_STA);
  WiFi.setHostname(DEVICE_NAME);
  WiFi.begin(WIFI_SSID, WIFI_PASS);
  Serial.printf("WiFi: connecting to \"%s\" in the background...\n", WIFI_SSID);

  consoleBegin();
  Serial.println("Bench relay console live on USB serial. Type 'help'.");
}

void loop() {
  // Bring up / keep up the network without ever blocking the relay console.
  if (WiFi.status() == WL_CONNECTED) {
    if (!netUp) startNetServices();
    ArduinoOTA.handle();   // must run continuously to receive OTA pushes
  } else if (millis() - lastWifiTry >= 5000) {
    lastWifiTry = millis();
    netUp = false;
    WiFi.reconnect();
  }

  consolePoll(netUp);    // read + dispatch any typed commands (USB always; telnet once netUp)
  Btns.update();         // debounce handlebar buttons; a press toggles its mapped relay
  Engine.update();       // run the engine-run state machine (drives the MASTER relay)

  // Onboard LED doubles as a bench indicator: heartbeat (proof of life) while
  // every relay is off; solid ON the moment any channel is energised — so you
  // get visible feedback even before the ULN/relay box is wired.
  if (Relays.anyOn()) {
    digitalWrite(PIN_LED, HIGH);
  } else if (millis() - lastBlink >= 1200) {
    lastBlink = millis();
    ledOn = !ledOn;
    digitalWrite(PIN_LED, ledOn);
  }
}

#endif  // PIO_UNIT_TESTING

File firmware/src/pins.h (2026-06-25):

// ===== pins.h — ESP32 GPIO map =====
// The single place that maps logical signals to physical ESP32 pins.
// Rationale and constraints are recorded in docs/adr/0009-gpio-pin-map.md.
//
// Relay enables are active-HIGH into the ULN2803A inputs. Every pin chosen
// here sits LOW at boot (none are strapping or flash pins), so all relays
// stay OFF while the ESP boots — which matches the 10 kΩ pull-downs on the
// ULN inputs and the accessory fail-OFF rule.
#pragma once

#include <Arduino.h>

// --- Relay coil enables (ULN2803A inputs 1..4) ---
constexpr uint8_t PIN_MASTER_EN = 13;   // external master relay (gates the whole box)
constexpr uint8_t PIN_FOG_EN    = 25;   // fog lights
constexpr uint8_t PIN_GRIP_EN   = 26;   // heated grips (future load)
constexpr uint8_t PIN_SPARE_EN  = 27;   // reserved aux channel

// --- Inputs (opto-isolated 12 V sense; logic inverts: 12 V present -> LOW) ---
constexpr uint8_t PIN_IGN_SENSE   = 34; // ignition/run-sense; input-only + RTC (ext0 wake)
constexpr uint8_t PIN_START_SENSE = 35; // start-button / headlight-feed sense; input-only + RTC
constexpr uint8_t PIN_IMU_INT     = 33; // IMU wake-on-motion interrupt; RTC (deep-sleep wake)

// --- I2C bus (INA3221 bus-voltage sense + 6-axis IMU) ---
constexpr uint8_t PIN_I2C_SDA   = 21;
constexpr uint8_t PIN_I2C_SCL   = 22;

// --- Aux buttons (ADR-0014): dry contacts, active-LOW with internal pull-up ---
// BTN1..BTN8; 7 used by the handlebar case + 1 spare. All pull-up-capable, no
// strapping/flash pins. Past 8 buttons -> MCP23017 on I2C (board rev, no re-wire).
constexpr uint8_t PIN_BTN[] = { 4, 14, 16, 17, 18, 19, 23, 32 };

// --- Onboard LED (heartbeat / bench relay-activity indicator) ---
constexpr uint8_t PIN_LED       = 2;

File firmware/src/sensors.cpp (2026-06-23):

// ===== sensors.cpp =====
#include "sensors.h"
#include "pins.h"
#include "log.h"

Sensors Sensor;

void Sensors::begin() {
  // IGN_SENSE is fed by the PC817 opto's pull-up (R9) in the real circuit; it
  // floats with no hardware, which is exactly why SIM mode is the default.
  pinMode(PIN_IGN_SENSE, INPUT);
  // TODO(INA3221): Wire.begin(PIN_I2C_SDA, PIN_I2C_SCL) + ina.begin() once the
  // board/driver is in hand; then busVoltage()'s real branch returns CH1.
  // Configure on-chip averaging (e.g. 64-128 samples) so the reading is already
  // low-pass-filtered against ADC noise / bus ripple before the supervisor's
  // charge-health logic sees it (pairs with that logic's hysteresis + debounce).
  LOGI("sensors: %s mode", sim_ ? "SIM" : "real");
}

float Sensors::busVoltage() {
  if (sim_) return simVbus_;
  // TODO(INA3221): return real CH1 bus voltage. Until the driver lands, the
  // real branch falls back to the sim value so nothing reads garbage.
  return simVbus_;
}

bool Sensors::ignition() {
  if (sim_) return simIgn_;
  // Opto inverts: 12 V present pulls the GPIO LOW => ignition ON.
  return digitalRead(PIN_IGN_SENSE) == LOW;
}

void Sensors::setSim(bool on) {
  sim_ = on;
  LOGI("sensors: %s mode", on ? "SIM" : "real");
}

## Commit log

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2026-06-19 Adding aditional ADRs and kicad kickoff
    [02-bom.csv, mainboard.kicad_pcb, mainboard.kicad_sch]
2026-06-22 hardware(mainboard): complete schematic + first-pass PCB layout
    [02-bom.csv, mainboard.kicad_pcb, mainboard.kicad_sch]
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2026-06-23 fix(supervisor): remove charge-warning threshold overlap
    [supervisor.h]
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2026-06-25 hw(mainboard): custom INA3221 footprint + handlebar button connector
    [02-bom.csv]
2026-06-25 hw(mainboard): INA3221 header pinout confirmed (1x8 VS/GND/SCL/SDA/PV/CRI/WAR/TC)
    Owner read the labeled header off the board: 8 pins, VS GND SCL SDA PV CRI WAR TC.
    Footprint rebuilt to 1x8 with those labels; only VS/GND/SCL/SDA are wired on the
    mainboard (the four open-drain alerts read over I2C, left NC). A0 is not on this
    header -> note the module default 0x40. Spec pin map + BOM updated to match.
2026-06-25 hw(mainboard): rename button connector J8 -> J10 (J8/J9 are the ESP sockets)
    The DevKitC's two socket headers already own J8/J9 in the schematic. Move the
    handlebar button connector to J10 across the spec + BOM to avoid the clash.
2026-06-25 hw(mainboard): INA3221 CH1 bus-sense goes off-board; drop J5/R14/C10 from PCB
    Decision: run the clean battery+ lead straight to the module CH1 IN+/IN- screw
    terminals (zero-current bus-voltage read); GND reference still via the header.
    CH1 is not on the 8-pin socket, so no on-board sense path is possible.
    - Remove J5 (sense terminal), R14 (series), C10 (filter) from the board.
    - D3 (SMBJ20A) kept as an OFF-BOARD clamp across the CH1 lead -> GND at the
    module/harness, preserving the INA 26 V input protection (ADR-0011).
    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
2026-06-25 hw(mainboard): schematic complete — INA3221 (U3), IMU (A2), 8 aux buttons (J10)
    Full board captured and ERC-clean:
    - U3 INA3221 on the 8-pin header symbol; VS/GND/SCL/SDA wired, PV/CRI/WAR/TC NC.
    - CH1 bus-sense is off-board (batt+ -> module CH1); J5/R14/C10/D3 removed.
    - A2 IMU reordered to VCC/GND/SCL/SDA/INT to match the physical board; INT->GPIO33.
    - J10 buttons: pins 1..8 -> R15..R22 -> GPIO 4/14/16/17/18/19/23/32, C11..C18 to
    GND, pin9 GND. Connector pin = button number.
    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
2026-06-26 hw(mainboard): final schematic + initial placement (precise module footprints)
    - U3 INA3221 on the precise 15-pad module footprint (Conn_01x15 symbol); VS/GND/
    SCL/SDA wired, PV/CRI/WAR/TC + channel terminals + VPU no-connect (CH1 off-board).
    - A2 IMU now GY-521 (8-pin): VCC/GND/SCL/SDA + INT on pin 8 -> GPIO33; XDA/XCL/AD0 NC.
    - MP1584 on the precise B22.1x16.8mm footprint.
    - Footprints placed in zones; ESP antenna overhangs the board edge; J8/J9 at 25.4mm.
2026-06-26 hw(mainboard): PCB routed + DRC-clean (0 errors)
    Two-layer board: power nets 1.5mm (12V_HOT/PROT, 5V, COIL_RAIL), +3V3 0.8mm,
    signals 0.3mm; GND pours both layers with stitching vias. ESP antenna overhangs
    the edge. All connectivity verified; remaining 28 DRC items are cosmetic silk
    overlaps only.
2026-06-29 hw(mainboard): BOM cleanup - passives to 0805, drop C6/C8, A2=GY-521
    - Flip signal passives to 0805 (R1-R4, R9-R13, R15-R22, C3/C4/C5/C7, C11-C18).
    R7/R8 stay 1206 for surge margin on the unprotected 12V sense side. Bulk
    electrolytics C1/C2, all connectors/terminals, and the modules stay THT.
    - Drop C6 (opto decoupling, unneeded) and C8 (spare) - never placed anyway.
    - C9 (10uF 3V3 bulk) marked optional (DevKitC already regulates 3V3; not on v1).
    - A2 corrected to GY-521 (MPU-6050) 8-pin: INT pin 8 -> GPIO33, addr 0x68.
    - Spec component list synced.
2026-06-29 hw(mainboard): all signal passives to 1206 (single SMD package)
    Every resistor (R1-R22) and ceramic cap (C3/C4/C5/C7, C9, C11-C18) -> 1206:
    one package to stock/order in bulk, easiest to hand-solder, ample power margin
    (R7/R8 surge headroom now inherent). Bulk electrolytics C1/C2 and all
    connectors/modules stay THT.
2026-06-29 hw(mainboard): split button connector J10 (1x9) -> J10 + J11 (2x 1x5)
    Two 1x5 JST-XH instead of one long 1x9: J10 = BTN1-4 + GND, J11 = BTN5-8 + GND.
    Easier to place/route, and lets the front/back button groups run as separate
    cables. Each connector carries its own ground. Updated spec (component list, ESP
    pin table, net table), BOM, and ADR-0014. Firmware unchanged (GPIO-based).
2026-08-23 hw(mainboard): checkpoint - restore clean PCB baseline; keep current schematic
    - Reset the broken reworked PCB (155 DRC violations) back to the DRC-clean 6867099
    board via git restore; the committed .kicad_pcb is again the known-good routed
    baseline (still the old J10 1x9 / THT-passive layout).
    - Preserve the current schematic (J10/J11 button split, GY-521 IMU, precise INA) -
    verified-correct and intentionally AHEAD of the restored PCB; the PCB gets
    re-synced to it when the layout is rebuilt.
    - gitignore .mcp.json (Konnect MCP config, machine-specific) + KiCad export cruft.
2026-10-31 hw(mainboard): fix input protection; re-lay out at 110x70 mm
    Protection fixes:
    - Q1 symbol to Q_PMOS_GDS (drain and source were swapped on the pads);
    part set to IRF4905 TO-220
    - connect the gate clamp (Dz1, R11) to +12V_PROT; R12 100R -> 10k
    - D1 SMBJ24A -> SMBJ16A so the clamp stays under the buck's 28 V limit
    - assign the coil output nets to the Power net class
    Layout: U2 to SOIC-18W, new 110x70 mm outline, 4 M3 holes, full re-route
    and GND stitching. DRC: 0 errors, 0 unconnected, parity 0.
    Add ADR-0015 and the enclosure and mounting notes.
2026-10-31 hw(mainboard): rename module footprints to include their size
    - INA3221_Module -> INA3221_Module_38.1x31.6mm (U3)
    - MP1584-Module_B22.1x16.8mm -> MP1584_Module_22.5x17.2mm (A3)
    - remove the unused first-pass MP1584_Module footprint
    Pads and routing are unchanged. DRC: 0 errors, 0 unconnected, parity 0.
2026-10-31 hw(mainboard): U2 to socketed DIP-18, hand assembly; clean up BOM
    - U2 back to DIP-18 in a socket (chips on hand); no JLCPCB assembly
    - re-place U2, re-route, re-stitch GND. DRC: 0 errors, 0 unconnected,
    parity 0
    - BOM now matches the schematic: drop D2, R13, C9, J7, TP1-4; add J8, J9
    and the mounting holes
    - D3 (off-board) to P6KE18A to stay under the INA3221 26 V limit
    - ESP32 row spacing confirmed 25.40 mm from the module drawing
2026-11-01 hw(mainboard): GY-521 footprint, INA3221 fixing holes, v1 gerbers
    Add a GY-521 footprint for A2 with pads in the socket's positions, so the
    routing is unchanged. Add board-only holes H5-H7 at the INA3221 module's
    mounting holes. Mark the ESP sockets optional and list the enclosure by
    minimum size in the BOM. Add the v1 gerber zip (DRC 0 errors).
2026-11-01 fw(buttons): runtime button mapping and factory loop scan (ADR-0016)
    Each input's relay and momentary/latching type is now saved in NVS and set
    from the console with btn map. Ring mode, on by default, reads the handlebar
    case's factory button loop by pulling BTN5 low, so all 7 buttons work on the
    supplied 7-wire cable. Turn it off with btn ring off once each button has its
    own wire. Native tests model the loop electrically.
2026-11-05 docs: put ULN COM and master coil on always-hot (ADR-0017)
    With ULN COM on the master-gated box rail and the master coil + on
    always-hot, the master's ULN output clamp diode back-feeds COM and the
    master relay energises itself. COM and the master coil + now both sit
    on always-hot; the box relays keep pin 86 on the gated box rail.
    Amends ADR-0003; updates the wiring schematic ULN detail, electrical
    plan section 21, bench guide and CLAUDE.md.
2026-11-05 hw(mainboard): 5-channel relay drive, J2 = master relay, re-route
    - ULN ch5 = AUX_EN on GPIO 12 (new 10k pull-down R23; keeps the strap
    LOW at boot). J3 now drives the four box relays (FOG/GRIP/SPARE/AUX).
    - J2 is the master-relay connector: J2.1 +12V_PROT (coil +),
    J2.2 COIL_MASTER (ULN ch1). ULN COM tied to +12V_PROT on-board.
    - ULN ch6-8 inputs to GND, outputs unconnected. COIL_AUX in the
    Power netclass.
    - Board re-routed from a blank slate with Freerouting; GND stitching
    vias join the pour fragments the coil and button tracks split up.
    DRC: 0 unconnected; only the known H5-H7 NPTH-in-U3-courtyard errors.
    - fab-v1 gerber zip regenerated.
    Headlight shed relay dropped: the headli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
2026-11-05 docs: five-channel relay drive, headlight off the ESP (ADR-0018)
    New ADR-0018: ULN ch1 = master relay on J2 (J2.1 always-hot coil +,
    J2.2 COIL_MASTER), ch2-5 = the four box relays on J3 (FOG/GRIP/SPARE/
    AUX), AUX_EN on GPIO 12 with a 10k pull-down that also holds the
    strap LOW (3.3 V flash). The headlight relay is a start-button-driven
    5-pin relay, bulbs on 87a, no ESP in the path; load-shed becomes
    grips -> fog only.
    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
2026-11-05 fw(relays): AUX relay channel on GPIO 12; versioned button mapping
    - RELAY_AUX ("aux") = GPIO 12 -> ULN ch5 -> J3.4. Console on/off/
    toggle/status/selftest and btn map accept it.
    - Button mapping NVS schema 2: "unmapped" is stored as a fixed 0xFF.
    Schema 1 stored RELAY_COUNT (4), which is now RELAY_AUX, so every
    unmapped button would have started driving AUX after this update.
    Schema-1 data is migrated once at boot.
    - Channel table is size-checked against RelayId at compile time.
    - Host tests: migration, aux mapping + persistence, unknown codes.
    Built for bench; native suites pass. Not yet run on the bench twin.
2026-11-05 hw(mainboard): tidy pull-down layout, title blocks, J6 value
    - Schematic: ULN pull-downs R1-R4/R23 redrawn on one GND rail for
    readability. No electrical change: all 74 nets identical to the
    previous commit; ERC 0 errors.
    - Title block on schematic and PCB (title, rev v1.0, company, notes).
    - J6 value set to INA3221 and synced to the PCB (DRC footprint
    mismatch cleared). Spec row updated.
2026-11-08 tools: guided relay test + console helpers (bench and bike modes)
    PC-side scripts that drive the ESP console over USB serial or Telnet,
    run with PlatformIO's bundled Python (pyserial):
    - run-relay-test.ps1 / relay_test.py: opens a window that says what to
    see/hear before each step. bench mode clicks relays 1-4, the master
    LED, all together, selftest; bike mode powers MASTER then fogs,
    grips (45 s hold), spare, aux. Both end with an EN-reset fail-OFF
    test. Ctrl+C switches every accessory off. Logs to tools/logs/.
    - esp_console.py: one-off commands, optional EN reset + boot log.
    - moto_serial.py: CP210x auto-detect, DTR never touched (no download
    mode), RTS reset, boot-clean / all-o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
2026-11-09 fw(sensors): INA3221 driver + sensors/i2c console; input watcher tool
    Firmware:
    - src/ina3221.{h,cpp}: library-free driver (ID check 0x5449/0x3220,
    all 3 ch, 128-sample averaging, ~0.85 s refresh). CH1 = battery sense.
    - sensors: real busVoltage() reads CH1 (100 ms cache). A missing chip
    or failed read gives 0.0 V, the fail-OFF reading: the supervisor never
    powers the box on a voltage it couldn't measure. The real branch no
    longer falls back to the sim value. Read failures log on transition
    only. Adds raw IGN/START pin reads for diagnostics.
    - console: `sensors` (INA CH1-3 + IGN/START pin levels), `sensors
    probe` (re-detect after hot-plug), `i2c` (bus scan).
    - platformio.ini: ben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
2026-11-09 fw(supervisor): debounce the ignition input (ignDebounce, 100 ms)
    The supervisor reacted to the raw IGN level on every pass, so key-switch
    contact bounce or a vibration dropout would immediately move RUNNING
    into OFF_DELAY. It now acts on a debounced ignition: a raw change must
    hold ignDebounceMs before it counts, in both directions, and any flicker
    back cancels the timer.
    - New runtime config key `ignDebounce` (ms, default 100, 0..2000; 0 =
    instant). No CONFIG_VERSION bump: a missing key loads its default,
    so stored settings survive (verified on the bench twin).
    - Tests: existing supervisor tests pin ignDebounceMs = 0. New tests
    cover a short key-on (ignored), held key-on (ARMED), a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
2026-11-09 tools(relay_test): LED bench mode; listen for the whole step
    - New -Mode leds: the same walk-through for the bench with one LED per
    ULN output (pin 18 master, 17 fog, 16 grip, 15 spare, 14 aux) instead
    of the relay box. The reset test uses the AUX LED.
    - cmd() now listens for the whole step before judging the reply.
    selftest takes ~3 s, and the old 1.5 s window reported a false
    NO REPLY. Flags garbled bytes on the USB line separately.
    - run-relay-test.ps1 waits for its window (like run-watch-inputs.ps1).
    Bench 2026-11-09: LED mode passed 14/14 with a clean reset test. One
    earlier run lost the first command to ~70 garbled bytes on the USB
    line; it was not reproducible.
    Co-Authore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
2026-11-09 tools: wake the serial line before step 1 (lost first reply)
    After the relay test waits at "Press Enter", the first command's reply
    came back as exactly 64 garbled bytes and the step was reported as NO
    REPLY (2 of 3 runs). The command itself reached the ESP: the FOG LED
    lit. Only the ESP->PC direction was corrupted, right after the port had
    sat idle. This is consistent with Windows power-saving the CP2102; the
    firmware is not involved.
    Esp.sync() sends a throwaway newline and a 'state' round-trip (up to 3
    tries) before step 1. Verified: the 64 garbage bytes now land inside
    sync() and the run is 14/14 with a clean reset test.
2026-11-10 fw: log 'would deep-sleep' once; add charge= to the state line
    In real-sensor mode with the key off, SLEEP printed "would deep-sleep
    here" on every loop, about 100 lines/s, which flooded the console. It is
    now logged once per SLEEP entry (sleepNoted_, cleared in enter()).
    The state line now ends with charge=ok|MARGINAL (or '-' outside
    RUNNING), so tools can check charge health from one snapshot instead
    of having to catch a log line.
    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
2026-11-10 tools: guided supervisor voltage walk; docs: INA3221 board + bench supply
    tools/voltage_walk.py with its launcher run-voltage-walk.ps1 run the
    engine-run state machine on REAL sensors. The owner sets the XY-SK35H
    bench supply and the IGN switch; the script checks each transition:
    SLEEP, ARMED, RUNNING + MARGINAL, recovered, POWERED, RUNNING,
    OFF_DELAY, SLEEP. Output printed while it waits for Enter is kept.
    Passed 9/9 on the bench twin.
    Docs: on the WCMCU-3221, CH1 is IN- and POW is the shared IN+, with a
    0.1 ohm shunt from POW to each channel. The GND holes beside the channels
    are ground. The old "tie CH1 IN+ and IN-" instruction was wrong for this
    board: jumpering CH1 to the adjacent GND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
2026-11-10 fw: load manager - engine-only grips, grips->fog shed ladder, crank hold
    Implements the manageLoads() hook from ADR-0012 as LoadManager
    (src/loads.{h,cpp}, ADR-0019). Buttons and the new 'loads want' console
    command record what the rider wants; the relays are driven to wanted
    AND allowed.
    - Grips are engine-only. They are held off unless the supervisor is
    RUNNING, and the request is remembered, so a pre-start press comes on
    once the engine runs.
    - Marginal charging sheds the grips, then the fog, one step per
    shedStep (30 s); loads that are already off are skipped. After
    recovery it restores fog, then grips, one per shedStep. Leaving
    RUNNING clears the ladder.
    - START held, plus cr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
2026-11-10 tools: loads profile for the voltage walk; docs: ADR-0019
    run-voltage-walk.ps1 -Mode loads walks the load policy on the
    FOG/GRIP/MASTER LEDs with the XY bench supply. It sets shedStep to 10 s
    for the walk and restores it afterwards. Steps are now declarative and
    can check the grip/fog relays and required log lines.
    Esp.sync() now keeps whatever it reads in sync_text, and the walk adds
    it to what it has seen. A log line that arrived during the wake-up
    right after Enter was lost before, which caused a false FAIL.
    Docs: ADR-0019 plus its index entry; CLAUDE.md (load manager, next
    steps); roadmap (load-shedding and START sense done); electrical-plan
    pseudocode.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
2026-11-10 fw: IMU security/crash logic - calibration, MOVED/BUMP/TIPPED, crash + cancel
    MotionMonitor (src/motion.{h,cpp}, ADR-0020) is pure logic fed at
    ~100 Hz from the main loop, together with whether the engine is
    RUNNING. It is unit-tested on the host with synthetic motion modelled on
    the bench unit's offsets.
    - 'imu cal' (still + upright, ~2 s) stores the gyro bias and the upright
    gravity vector in NVS. Stillness is judged by per-axis std dev, so a
    single bad sample no longer fails a still calibration.
    - Context: RIDING = engine RUNNING now or within 10 s (a crash stalls
    it); PARKED otherwise.
    - Events:
    - BUMP (parked knock);
    - MOVED (parked attitude change > moveDeg for 1 s, re-armin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
2026-11-10 tools: guided security/crash walk; docs: ADR-0020
    tools/security_walk.py with run-security-walk.ps1 walks the IMU event
    logic on the bench: park reference, MOVED, re-arm, BUMP, TIPPED,
    UPRIGHT, and a crash with auto-cancel. For the crash step it fakes the
    engine as RUNNING in SIM and lowers crashG to 1.5 g, then restores
    both. It offers 'imu cal' if the IMU isn't calibrated.
    Docs: ADR-0020 (and its index entry), CLAUDE.md firmware notes and
    milestone, tools README.
2026-11-12 hw(mainboard): INA3221 footprint - unhook POW/GND holes from GND, fix CH silk
    The custom INA3221_Module footprint numbered the WCMCU-3221's POW hole
    and its neighbouring GND hole as pad 2, which put them on board GND.
    POW is the shared IN+ of the 0.1 ohm shunts. With the battery sense lead
    on CH1, that is a dead short through the CH1 shunt: the same fault as
    the bench jumper that likely killed ESP #1. The owner caught it in the
    pre-fab review.
    - Both holes now have no pad number, so they can never take a net. The
    module's GND comes only through header pin 2.
    - The big-hole silk now matches the real module (GND/CH1/GND/CH2/GND/CH3
    instead of CHx+/CHx-).
    - The board was updated from the l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
2026-11-12 hw(mainboard): drop stale v1 gerbers zip
    mainboard-v1-gerbers.zip dates from 2026-11-01. It predates the
    5-channel relay drive (64da742) and the INA3221 POW/GND fix (4d4686b),
    so it still has the POW-to-GND short. Fab outputs are now regenerated
    from the board before each order and kept out of git.
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2026-11-13 hw(mainboard): GY-521 mounting holes H8/H9, +5V re-routed clear of H9
    Two 3.2 mm NPTH holes at the module's own hole positions:
    - H8 (141.04, 87.57) and H9 (156.28, 87.57), so the IMU can be fixed with
    spacers;
    - marked "not in schematic";
    - use nylon hardware: relay coil traces run on B.Cu about 2.3 mm from
    the hole centres.
    The 1.5 mm +5V trace from the MP1584 to the ESP 5V pin passed within
    0.04 mm of H9's edge. It now doglegs via (153, 87.7) and (153, 90.5) to
    y = 92, about 3 mm clear of the hole.
    DRC: 0 unconnected, 0 parity issues. The only new items are H8/H9
    inside A2's courtyard, which is intended (same as the INA3221 holes).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
2026-11-14 tools: jlc_assembly - one BOM line per LCSC part, SOIC-8 rotation fix
    - JLC rejects the same LCSC part on two BOM lines, which happened when the
    same capacitor was written "100n" and "100nF", and for the four LEDs
    labelled OUT5..OUT8. The BOM is now grouped by (footprint, LCSC).
    - ROTATION_FIX table, per footprint. SOIC-8 (TC4427A) needs +270 in the
    CPL. Note: JLC's viewer and the CPL file count rotation in opposite
    directions (viewer 90 = CPL 270), so confirm a correction by
    re-uploading the CPL.
2026-11-14 tools: jlc_assembly - LED 1206 rotation fix (+180) for the XL-3216UGC
    JLC's model put the cathode on the wrong pad of pwm-board D5-D8; KiCad pad 1 (K, GND) is the bottom pad.

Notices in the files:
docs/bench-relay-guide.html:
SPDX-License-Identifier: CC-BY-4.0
